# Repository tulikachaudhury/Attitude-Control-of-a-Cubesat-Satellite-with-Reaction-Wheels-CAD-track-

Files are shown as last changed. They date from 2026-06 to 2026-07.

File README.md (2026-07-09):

# Attitude-Control-of-a-Cubesat-Satellite-with-Reaction-Wheels-CAD-track-
Designing a 3U cubesat satellite with at T3 mutually perpendicular reaction wheels for attitude control, wheel mounting brackets, motor housing and structural supports. Ensure the design is dimensionally consistent and physically plausible.

<ins>The decision to use a 3U form factor</ins>
| Parameter | 1U | 2U | 3U |
| --- | --- | --- | --- |
| Volume | Small | Medium | Large |
| Wheel Integration | Difficult | Moderate | Easy |
| CAD Complexity | Easy | Medium | Medium |
| Realism | Moderate  | Good | Excellent |

The 1U form factor faces a volume crisis, allowing no room for a payload.
The 2U form factor does allow space for a small payload but the asymmetric physics due to the centre of mass lying between the 2 1U units make it an unfavourable choice. Moreover, the 2U form factor is much less common in the industry so it is hard to find references.
The 3U form factor ultimately wins out as the segments can be divided cleanly(payload, ADCS, avionics), and it solves the centre of mass and volume issues. The larger surface area also allows for massive power generation from solar panels. 
The 3U CubeSat has become the industry standard for commercial applications, offering the optimal balance between payload capacity, power generation, and cost-effectiveness. Companies like Planet Labs operate entire Earth observation constellations using 3U Dove satellites, while 6U and 12U platforms enable more sophisticated missions including deep space exploration and advanced propulsion systems.

<ins>The Design Process</ins>
The Chassis
The rails must be the longest part of the body, therefore a standoff offset of 2mm on either side is taken.
As stated in the Cal Poly blueprint, I have followed the standoff contact detail by using chamfer, and the max allowable protrusion on the faces is the rail width. Trusses between the rails ensure a lightweight and sturdy design, and fillets were added to the outer edges to ensure that sharp corners do not cause damage. Aluminium 6061 was my material of choice for the chassis

ACDS Design
Motor : EC22 Flat L High Torque
Reaction Wheel Diameter: 35m
Reaction Wheel Thickness: 8mm
The 3 mutually perpendicular wheels are placed at azimuths of 0 degrees, 120 degrees and 240 degrees. 

References:
International Journal of Aerospace
hexstaruniverse.com
nanoavionics.com

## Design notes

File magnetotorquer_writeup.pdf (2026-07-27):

## Magnetotorquer Design: The Math, the Logic, and the Numbers

Tulika Chaudhury

July 27, 2026

## Why we need these at all

The satellite has three reaction wheels, each tilted at cos⁻¹ (1/

√
3) ≈ 54.74◦
from the Z axis and
spaced 120◦ apart in azimuth. Dotting the three spin-axis unit vectors pairwise gives zero in all three cases, confirming they’re genuinely mutually orthogonal despite none of them lying along a body axis – a deliberate choice that gives equal torque and momentum capability in every direction using only three actuators.
Reaction wheels are excellent for fine pointing, but they only move angular momentum around – from the spacecraft body into the spinning wheel and back – they never get rid of it. Any small, steady external torque (gravity gradient, atmospheric drag, sunlight pressure, the satellite’s own stray magnetism) makes the wheels absorb momentum faster than they release it, and their speed creeps up orbit after orbit until one saturates and stops being able to produce torque at all. Magnetotorquers fix this because they push against something external – Earth’s magnetic field – so they can actually remove momentum rather than just shuffle it. They do two jobs: detumbling right after deployment, when body rates are too high for the wheels to safely absorb, and periodic momentum “dumping” during normal operation to keep the wheels in their healthy range.

## The physics, in plain terms

A current-carrying coil makes a magnetic dipole – a tiny switchable bar magnet – of strength

m = NIA, | (1)

where N is the turn count, I the current, and A the enclosed area. A magnetically soft core inside the coil concentrates the field and boosts this for the same current:

m = µrod NIAcore. | (2)

Immersed in Earth’s field B, that dipole feels a torque

τ = m × B. | (3)

The cross product matters: torque is always perpendicular to B, so a torquer can never twist the spacecraft about the direction the field happens to point at that instant. That’s why three axes are needed – between them, and as B rotates through the body frame over an orbit, they cover everything.

Why a rod doesn’t get the full benefit of its core

A finite rod partially cancels its own field at the ends – the same reason a short bar magnet is weaker than a long one of the same material. This self-demagnetization is captured by a demagnetizing factor Nd, which for a rod of length L, diameter d (aspect ratio ℓ = L/d) is approximately

Nd ≈

ln(2ℓ) − 1
ℓ

2

, | (4)

knocking the bulk material permeability µr down to an effective

µrod =

µr
1 + Nd(µr − 1). | (5)

The shorter the rod, the harder this bites.

How the satellite decides when and how hard to fire the coils

Detumbling. With only a magnetometer to work from, the standard approach is the B-dot law:

mcmd = −k B˙
body ≈ k (ω × B). | (6)

While tumbling fast, the field as seen by the satellite changes mostly because the satellite is spinning, not because the field itself moves. Commanding a dipole proportional to that apparent rate of change produces a torque that always opposes the part of the spin perpendicular to B – a magnetic brake needing nothing more than a magnetometer.

Momentum dumping. Once wheel momentum hw needs shedding, the desired de-saturation torque is τ des = −khhw. Since only the component perpendicular to B is achievable at any instant, the best available command is the projection

mcmd =

B × τ des
|B|

2

. | (7)

As B rotates through the body frame once per orbit, every component of hw eventually gets its turn to be perpendicular to the field, so it all comes off over time.

## How big does the dipole need to be?

Table 1: Worst-case steady disturbance torque, 500 km LEO.
Source | Size | Notes
Gravity gradient | 20.6 nN m | from the CAD inertia tensor
Aerodynamic drag | 43.2 nN m | 2 cm CG/CP offset
Solar radiation pressure | 4.9 nN m | smallest contributor
Residual spacecraft dipole | 400 nN m | dominates; 0.01 A m² residual
Total | 469 nN m | linear (conservative) sum

The satellite’s own stray magnetism – current loops in the avionics stack – dominates this budget, outweighing gravity, drag, and sunlight pressure combined (Figure 1).

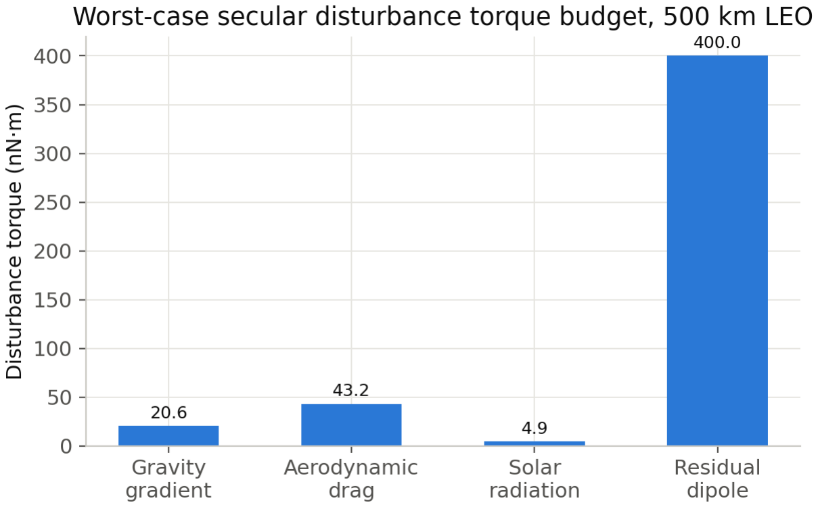
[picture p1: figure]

Figure 1: Where the disturbance torque comes from.

Sizing rule: double the disturbance torque for margin, and use the weakest field likely in orbit (near the geomagnetic equator, Bmin ≈ 25 µT at 500 km):

mreq =

2 τdist

Bmin

=

2 × 4.69 × 10⁻⁷
2.5 × 10⁻⁵

≈ 0.038 A m²
. | (8)

That’s the number every axis needs to beat.

## Sizing the actual hardware

X and Y use a 4 mm diameter steel core with a 14 mm outer diameter copper winding, 60 mm rod length, wound over 50 mm of it. Z runs along the 340.5 mm long axis of the 3U stack, so a rod there would be impractically long and would collide with the wheel array, avionics stack, and payload bay – an air-core coil bonded flat to the top bulkhead avoids that.

X/Y rods

Core cross-section: Acore = π(2mm)² = 1.257 × 10⁻⁵ m² . With L = 60 mm, d = 4 mm, the aspect ratio is ℓ = 15, so self-demagnetization matters:

Nd =

ln(30) − 1
15²

= 0.0107, µrod =

1000
1 + 0.0107(999) ≈ 86,

using µr = 1000 for the core steel. That’s how a bulk permeability of 1000 collapses to an effective 86 once the rod’s own shape is accounted for.
Design point: 600 turns of AWG28 magnet wire (0.36 mm insulated), 100 mA. Over the 50 mm winding length, AWG28 fits about 138 turns per layer, so 600 turns needs 5 layers – a 1.8 mm radial build-up, well inside the 5 mm annular space between core and coil OD. Resistance comes out to about 2.3 Ω, so each rod draws roughly 23 mW at 100 mA, and delivers

m = µrodNIAcore ≈ 0.065 A m² ,

about 70% above the 0.038 A m²
requirement.

Z air coil

No core, so µ = 1 in Eq. (2). Using an 80 mm outer diameter coil on the 100×100 mm top bulkhead, 100 turns of AWG28 at 100 mA:

Acoil = π(0.04 m)² = 5.03 × 10⁻³ m² , m = NIAcoil ≈ 0.050 A m² ,

about 32% above requirement. Wound as roughly 10 turns radially by 10 layers stacked (a compact ∼3.6 mm × 3.6 mm cross-section), it needs about 24 m of wire, giving R ≈ 4.9 Ω and P ≈ 49 mW at 100 mA.

Table 2: Magnetorquer design summary.
Axis | Construction | Turns | R (Ω) P @100mA | m delivered
X | 4mm core / 14mm coil, L=60mm | 600 | 2.3 | 23 mW | 0.065 A m²
Y | 4mm core / 14mm coil, L=60mm | 600 | 2.3 | 23 mW | 0.065 A m²
Z | 80mm air coil, top bulkhead | 100 | 4.9 | 49 mW | 0.050 A m²

All three clear the 0.038 A m²
requirement with margin (Figure 3), and total simultaneous power draw is under 100 mW – a rounding error against a typical 3U power budget. In practice the axes are usually pulsed one at a time, so real draw is lower.

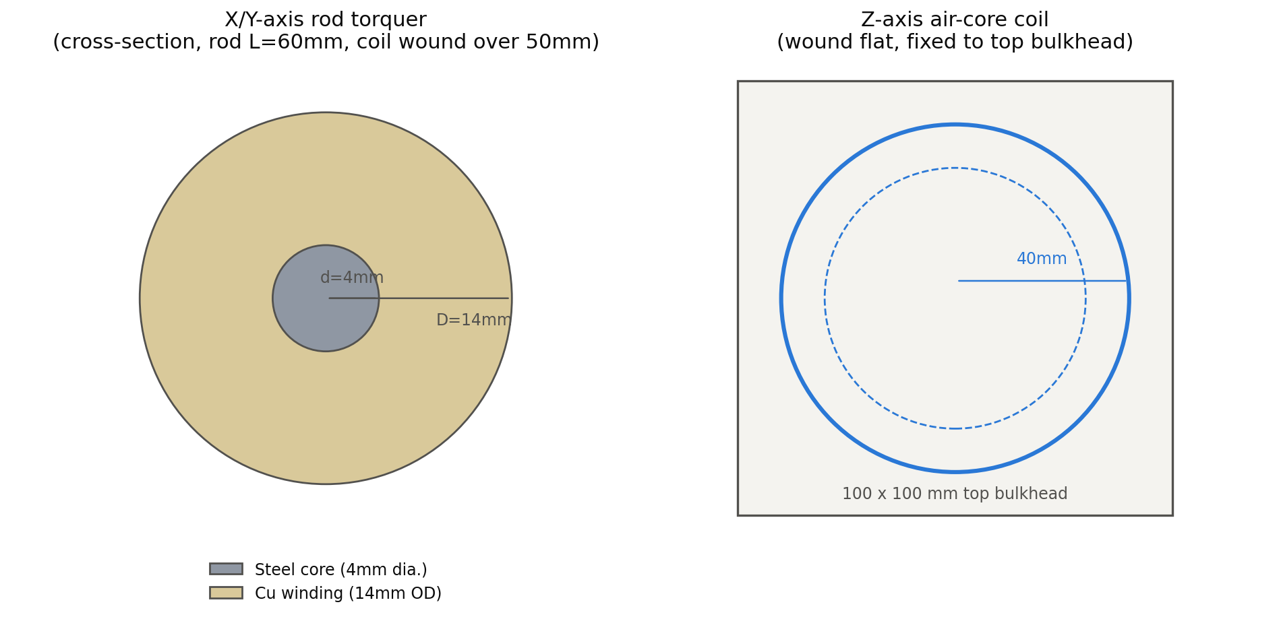
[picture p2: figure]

Figure 2: Left: rod cross-section. Right: the Z-axis coil’s footprint on the top bulkhead.

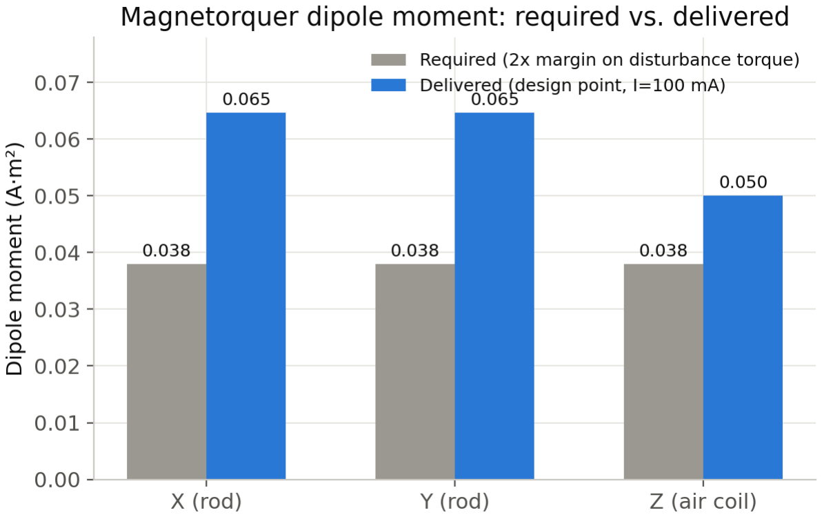
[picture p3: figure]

Figure 3: Required versus delivered dipole moment, by axis.

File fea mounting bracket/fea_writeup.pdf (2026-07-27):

## Reaction-Wheel Mounting Bracket: Launch-Load FEA

Tulika Chaudhury

July 27, 2026

## What this is and why it matters

Each of the satellite’s three reaction wheels sits in its own mounting bracket – an angled plate braced by two gussets, bolted down through a base flange, holding the Maxon ECX FLAT 22 L motor at the wheel’s spin-axis tilt. That tilt isn’t arbitrary: the three wheels are mutually orthogonal, each one skewed cos⁻¹
(1/

√
3) ≈ 54.74◦

from the Z axis, spaced 120◦ apart in azimuth. Measuring the actual motor-seating face directly off the CAD file gives an incline of 35.26◦ from the base plane –
which is exactly the complement of 54.74◦
, a nice confirmation that the bracket geometry matches the intended wheel orientation.
Before anything gets built, it’s worth asking a very ordinary question: will this bracket survive being launched? Rockets shake hard, and a small, light metal part cantilevered off a base plate is exactly the kind of thing that can crack or resonate itself apart if it’s under-designed. This is a finite-element analysis (FEA) of that bracket, run directly on the CAD file you uploaded – not a simplified stand-in – under a launch load case.

## The load case, explained

”Launch loads” for a small structure like this usually gets simplified to a quasi-static check: instead of simulating the actual shaking (a full random-vibration analysis), you pretend the whole structure is sitting in a very strong, steady gravity field and see if it survives. 12g is a standard, conservative number to use for this kind of check absent a specific launch-vehicle spec – it’s meant to be a worst-case stand-in for what several seconds of real vibration would do, not a literal prediction of any one moment.
We ran that 12g load three times, once pushing along each of the body’s X, Y, and Z axes, because a bracket that’s strong in one direction can be weak in another. On top of the 12g itself, we also add a safety factor of 1.25 when judging whether the design has survived – standard practice, so the reported margin already has some conservatism baked into it.
The load itself comes from two places: the bracket’s own (small) mass, and the motor plus one flywheel bolted to it – 32 g for the Maxon motor (from its published datasheet) plus 6.55 g for a flywheel (a quarter of the 26.2 g total across the wheel set), so 38.55 g all told. That mass is modeled as sitting rigidly on the four screw holes where the motor actually bolts on, offset about 10 mm out from the mounting face to approximate where the combined motor + flywheel center of gravity actually sits.

## How the model was built

The bracket was meshed with 24,332 nodes and 14,167 quadratic tetrahedral elements, refined down to 0.35 mm near the small bolt and screw holes where stress tends to concentrate. Every element passed a positive-Jacobian check before solving, meaning there are no inverted or degenerate elements corrupting the result.
For material, we used Aluminium 7075-T6 (E = 71.7 GPa, yield strength 503 MPa) as the primary case, since this is a stress-concentration region (gusseted corner, small bolt holes) – exactly where the stronger alloy earns its keep. We also checked Aluminium 6061-T6 (yield 276 MPa) side by side; the stress field itself barely changes between the two alloys (stress here depends on geometry and load, not much on which aluminum you pick), so this comparison is really just a second yieldstrength check, not a second analysis.
The base flange – the four bolt holes where the bracket clamps to the central mounting plate – was treated as fully fixed, standing in for a properly torqued bolted joint.

## What we found

Table 1: Peak stress, deflection, and margin of safety, by load direction.
Load case | Peak stress (raw) Peak stress (field)¹ Max deflection | MS, 7075-T6 | MS, 6061-T6
12g, +X | 1.37 MPa | 1.19 MPa | 0.12 µm | +293 | +160
12g, +Y | 2.56 MPa | 2.16 MPa | 0.23 µm | +156 | +85
12g, +Z | 2.83 MPa | 2.43 MPa | 0.21 µm | +141 | +77

Margin of safety here is MS = Sy/(1.25 × σvm) − 1, so a margin of, say, +150 means the part could handle roughly 150 times today’s stress before yielding. These numbers are enormous – deliberately so, because it’s worth showing rather than just asserting. A couple of milli-newtons of force spread across a few millimeters of aluminum just doesn’t add up to much stress, and that’s the honest physical reason, not an error. Figure 1 shows where that stress actually concentrates (the base flange corner nearest the bolt holes, exactly where you’d expect a clamped bracket foot to work hardest), and Figures 2–3 show the same numbers as charts.

1The raw column includes a node sitting exactly at a fixed-corner/bolt-hole edge – FEA reliably reports an artificially high, mesh-dependent stress right at a perfectly clamped sharp corner, which isn’t a physical material limit. The field column excludes those boundary nodes and is the more honest number; either way the story doesn’t change.

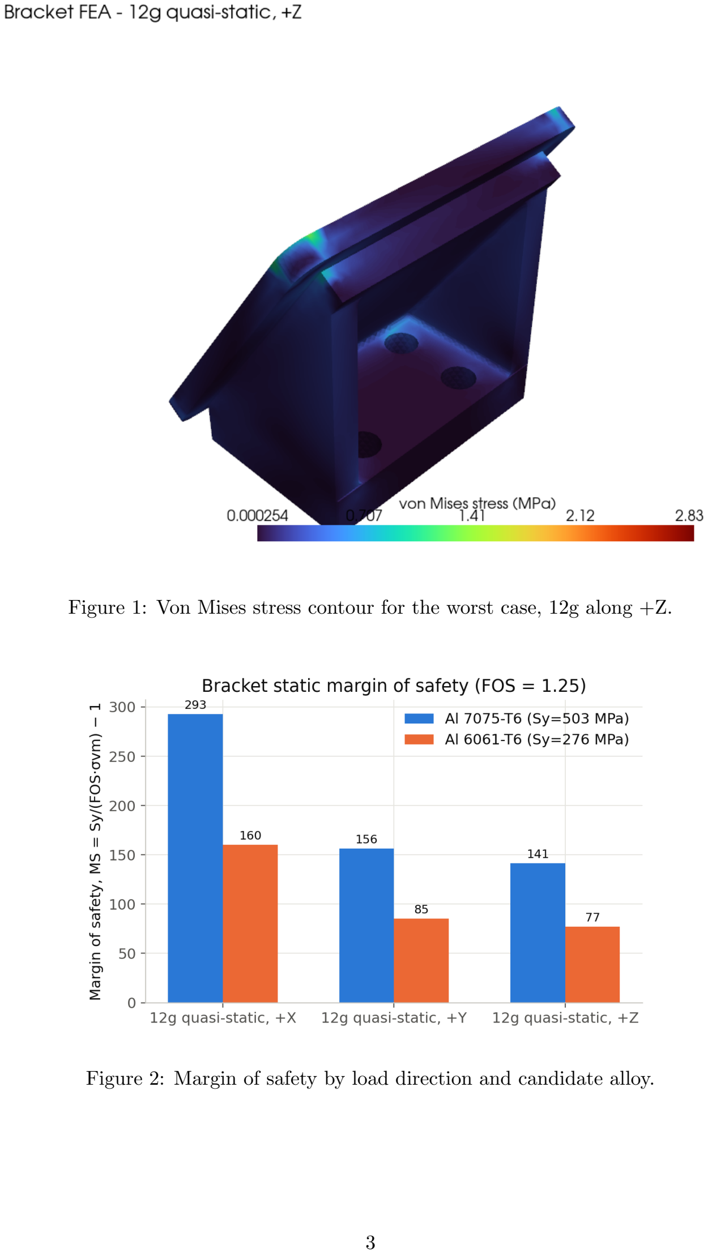
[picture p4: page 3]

Figure 1: Von Mises stress contour for the worst case, 12g along +Z.

Figure 2: Margin of safety by load direction and candidate alloy.

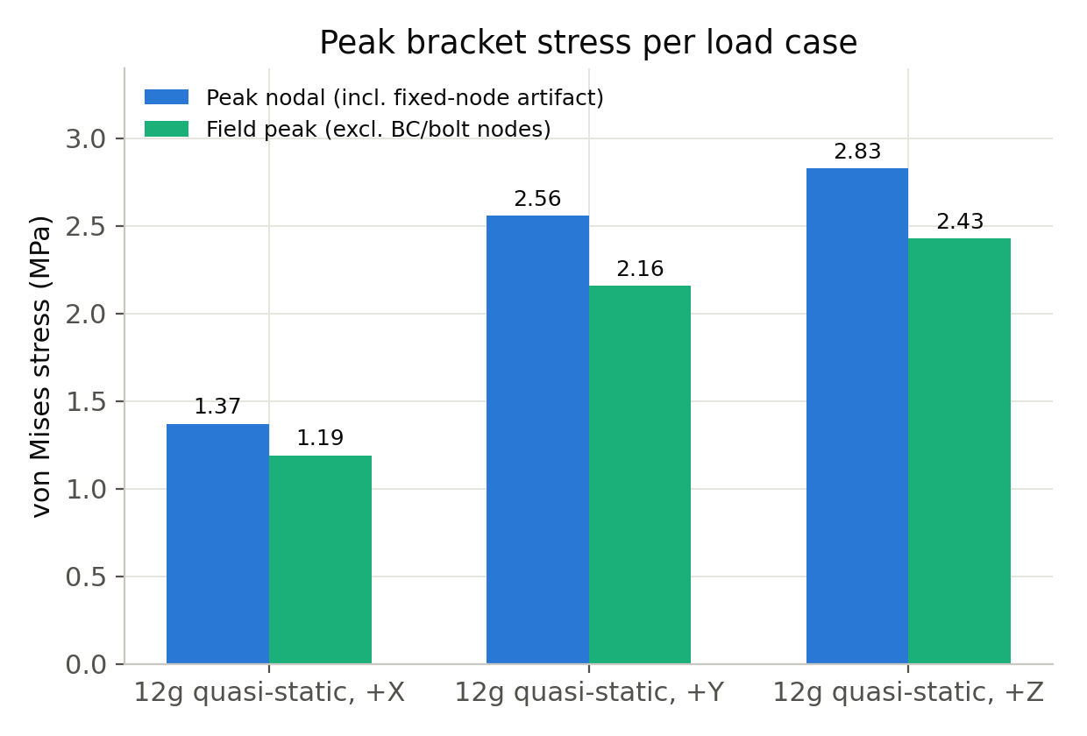
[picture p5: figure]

Figure 3: Peak stress per case: the raw (boundary-affected) number next to the more honest field number.

## The frequency check, and why it’s the number that actually matters here

Once the stress margins came back this large, stress stops being the interesting question. The thing that actually decides whether a small, stiff bracket like this survives a real launch is its natural frequency – how it wants to vibrate on its own. Rockets shake across a broad range of frequencies, and if a part’s natural frequency sits too low, it can resonate with that shaking and take far more damage than a simple g-load estimate would suggest, even if the static stress numbers look fine. Using the same fixed-base model with the motor and flywheel mass attached, the bracket’s first natural frequency comes out to about

f1 ≈ 4122 Hz,

which is comfortably – by a factor of 40 or so – above the roughly 100 Hz minimum stiffness that CubeSat deployer specifications typically require. This bracket is not going to be the thing that resonates on the way up.

## Limitations and scope

Two limitations are worth stating clearly, since they affect how these results should be read.
The 12g load case is a quasi-static approximation, not a full random-vibration analysis. It is the standard first screen for a structure of this size, and it is what launch loads means in this context, but a complete random-vibration (PSD) study remains the appropriate next step before the bracket can be considered launch-qualified.
The highest stress value in the raw results occurs at a mathematically singular point – a perfectly clamped sharp corner, where any finite-element model will report an artificially high, mesh-dependent stress that does not correspond to a physical material limit. Table 1 therefore reports both this raw value and a field value that excludes the boundary nodes responsible for the artifact; the conclusion is unchanged either way.

## Bottom line

The bracket clears launch quasi-static loading with very large margin in every direction tested, and its first natural frequency sits well clear of typical CubeSat stiffness requirements. It isn’t a structural risk item as designed – if anything, there may be room in a later iteration to shave material for mass savings, since the part is clearly over-built relative to what the loads actually demand.

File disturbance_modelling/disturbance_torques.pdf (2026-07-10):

## Environmental Disturbance Torques on a 3U CubeSat

ADCS Team — Simulation Track

July 10, 2026

Abstract

A reaction-wheel attitude control system must reject the small but persistent external torques that act on a spacecraft in low Earth orbit. This note derives, from first principles, the four dominant environmental disturbance torques for our 3U CubeSat reference mission (a 500 km Sun-synchronous orbit): the gravity-gradient torque, aerodynamic drag torque, solar radiation pressure torque, and residual magnetic torque. For each, we state the physical origin, derive the governing equation, and evaluate the order of magnitude for our platform. All four are of order 10⁻⁹ N m to 10⁻⁶ N m; over an orbit they pump momentum into the wheels, which is periodically removed by magnetorquer desaturation.

## 1 Reference Parameters

All numerical estimates use the reference mission and CAD-derived properties in Table 1.

Table 1: Reference orbit and spacecraft parameters.
Quantity | Symbol | Value
Orbit altitude | h | 500 km
Orbit radius | r | 6878 km
Orbital speed | v | 7613 m/s
Mean motion | n | 1.107 × 10⁻³ rad/s
Max transverse inertia | Imax | 1.405 × 10⁻² kg m²
Min inertia (spin axis) | Imin | 2.889 × 10⁻³ kg m²
Long-face area | A | 0.034 m²
Centre-of-pressure offset | rcp | 0.02 m
Earth magnetic field (LEO) B | 2 × 10⁻⁵ T to 5 × 10⁻⁵ T

The body-to-inertial rotation matrix built from the attitude quaternion q is written R(q); its transpose R(q)

⊤ maps an inertial vector into the body frame. All torques below are expressed in the body frame, because that is where Euler’s equation is integrated.

## 2 Gravity-Gradient Torque

Physical origin

Earth’s gravity is stronger on the near side of the spacecraft than the far side. For an extended body this differential pull produces a torque that tends to align the axis of minimum inertia with the local vertical.

Derivation

Model the body as a collection of point masses mi at positions r

c
i

relative to the centre of mass (CoM). The gravitational force on each is expanded to first order about the CoM,

Fi ≈ mi

g(r

c0
) + G(r

c0
) r

c
i
, | (1)

where G = ∂g/∂r is the gravity-gradient tensor at the CoM. The total torque about the CoM is L =

P
i

r

c
i × Fi

. The uniform part P
i mir

c
i
× g vanishes identically, because P
i mir

c
i = 0 by
the definition of the centre of mass. Only the gradient term survives; carrying out the sum (which turns the mass distribution into the inertia tensor J) and specialising to a spherical Earth gives the standard result
τgg = 3n

2 oˆ ×
J oˆ
(2)

where oˆ = R(q)

⊤ oˆinertial is the nadir (satellite → Earth) unit vector expressed in the body frame, and n is the orbital mean motion.

Key properties

The torque vanishes when a principal axis points at nadir, since then oˆ is an eigenvector of J and oˆ × Joˆ = 0. This is the basis of passive gravity-gradient stabilisation.

It is attitude-dependent: it must be recomputed every integration step.

Order of magnitude

The worst-case magnitude is

τ

max
gg =

3/2 n

2
Imax − Imin
=

3/2(1.107 × 10⁻³
)

2

(1.405 × 10⁻² − 2.889 × 10⁻³

) ≈ 2.1 × 10⁻⁸ N m. (3)

## 3 Aerodynamic Drag Torque

Physical origin

Even at 500 km the residual atmosphere exerts a drag force on the spacecraft. If the centre of pressure (CP) does not coincide with the CoM, this force produces a torque.

Derivation

The drag force opposes the velocity direction vˆ and has magnitude

Fdrag = −

1/2 ρ v² Cd A vˆ, | (4)

with ρ the local atmospheric density, v the orbital speed, Cd the drag coefficient (typically 2.2 for free-molecular flow), and A the projected frontal area. Expressed in the body frame and applied at the CP offset rcp from the CoM, the torque is

τaero = rcp ×

R(q)

⊤Fdrag
(5)

Order of magnitude

With ρ ≈ 5 × 10⁻¹³ kg/m³
(moderate solar activity), v = 7613 m/s, Cd = 2.2, A = 0.034 m² :

Fdrag =

1/2(5×10⁻¹³)(7613)²

(2.2)(0.034) ≈ 1.1×10⁻⁶ N, τaero ≈ Fdrag rcp ≈ 2.2×10⁻⁸ N m. (6)

Density varies by an order of magnitude with solar activity, so ρ is treated as a tunable parameter in the simulation.

## 4 Solar Radiation Pressure (SRP) Torque

Physical origin

Sunlight carries momentum; photons striking the spacecraft exert a small pressure. As with drag, an offset between the centre of pressure of the illuminated surface and the CoM converts this force into a torque.

Derivation

The solar radiation pressure at Earth’s distance is P = Φ/c, where Φ ≈ 1361W/m² is the solar
flux and c the speed of light, giving P ≈ 4.56 × 10⁻⁶ N m⁻²
. The force on an illuminated area As with reflectivity q (0 = perfectly absorbing, 1 = perfectly reflecting) is
Fsrp = −P (1 + q) As sˆ, | | (7)

with sˆ the Sun-to-spacecraft unit vector. The resulting torque about the CoM, with solar-pressure centre offset rcps, is

τsrp = rcps ×

R(q)

⊤Fsrp
(8)

The torque is present only in sunlight (zero during eclipse), so for a Sun-synchronous orbit it acts as a roughly once-per-orbit modulated disturbance.

Order of magnitude

With q = 0.6, As = 0.034 m² , rcps = 0.02 m:

Fsrp = (4.56 × 10⁻⁶

)(1.6)(0.034) ≈ 2.5 × 10⁻⁷ N, | τsrp ≈ 5.0 × 10⁻⁹ N m. | (9)

This is the smallest of the four for our platform, but for missions with large deployed solar panels (large As and rcps) it can dominate.

## 5 Residual Magnetic Torque

Physical origin

The spacecraft has a small residual magnetic dipole m arising from current loops, permanent magnets in components, and magnetised materials. This dipole interacts with Earth’s magnetic field B, producing a torque — the same physics the magnetorquers use deliberately for desaturation, here acting as an unwanted disturbance.

Derivation

The torque on a magnetic dipole m in an external field B is

τmag = m × B | (10)

where m is the body’s residual dipole (body frame, in A m²
) and B = R(q)

⊤Binertial is the local
geomagnetic field in the body frame. The field magnitude in LEO is B ≈ 2 × 10⁻⁵ T to 5 × 10⁻⁵ T and reverses roughly twice per orbit as the spacecraft crosses the magnetic equator, so this torque is strongly attitude- and position-dependent.

Order of magnitude

A typical uncompensated CubeSat residual dipole is m ≈ 0.01 A m²

to 0.05 A m²
. Taking m =
0.02 A m² and B = 3 × 10⁻⁵ T:

τmag ≈ (0.02)(3 × 10⁻⁵

) ≈ 6 × 10⁻⁷ N m. | (11)

This is often the largest of the environmental disturbances for a small satellite, which is why minimising the residual dipole (magnetic cleanliness) is a standard design driver.

## 6 Summary and Implications

Table 2 collects the four torques. All are of order 10⁻⁹ N m to 10⁻⁶ N m — individually tiny, but secular : acting continuously, they steadily accumulate angular momentum in the reaction wheels.

Table 2: Environmental disturbance torques for the 3U reference mission.
Disturbance | Governing equation | Magnitude (N m)
Gravity gradient | 3n
| 2 oˆ × (Joˆ) | ∼ 2 × 10⁻⁸
Aerodynamic drag | rcp × Fdrag | ∼ 2 × 10⁻⁸
Solar radiation press. | rcps × Fsrp | ∼ 5 × 10⁻⁹
Residual magnetic | m × B | ∼ 6 × 10⁻⁷

Momentum accumulation and desaturation. Because a reaction-wheel array conserves total angular momentum, any secular disturbance τd is absorbed by the wheels, whose stored momentum grows approximately linearly, hw(t) ≈ τd t. The wheels saturate at tsat = hmax/τd. For our platform (hmax ≈ 7 × 10⁻³ N m s) under the combined disturbances (∼ 7 × 10⁻⁷ N m worst case), tsat is of order a few hours, after which the magnetorquers must remove the accumulated momentum by applying a commanded τ = mcmd × B against Earth’s field. This is the physical justification for including magnetorquers in the ADCS architecture.

Modelling scope. The simulation implements the gravity-gradient and aerodynamic-drag torques directly (Eqs. 2 and 5), with all parameters exposed in the configuration file. Solar radiation pressure and magnetic torque are documented here for completeness and can be added as further terms in the same disturbance module; each reduces to a body-frame cross product of the form already implemented.

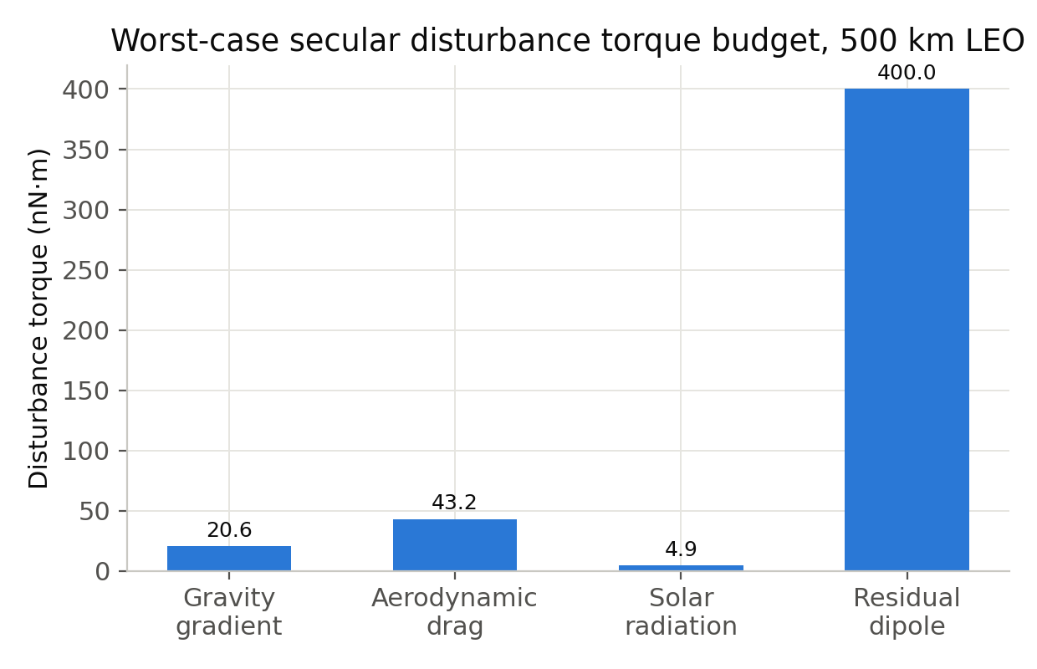
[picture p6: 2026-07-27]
fea mounting bracket/plot_disturbance_budget.png

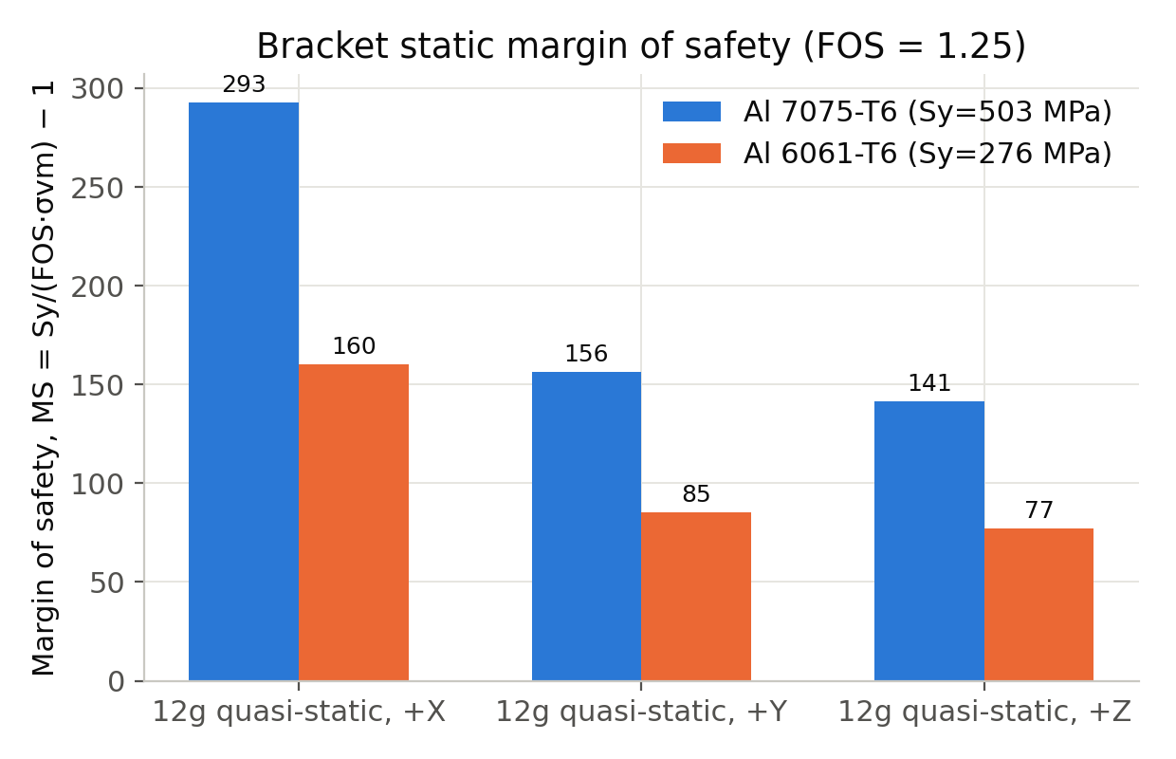
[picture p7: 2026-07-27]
fea mounting bracket/plot_margin_of_safety.png

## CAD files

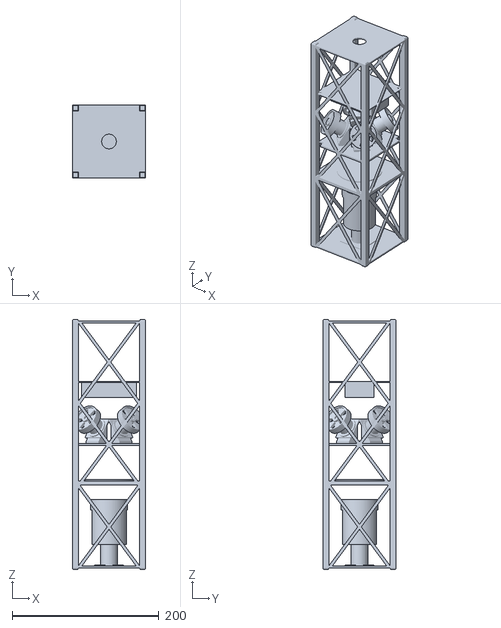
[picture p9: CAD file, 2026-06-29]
3U_Cubesat_Master_version2.stl
100.0 x 100.0 x 340.5

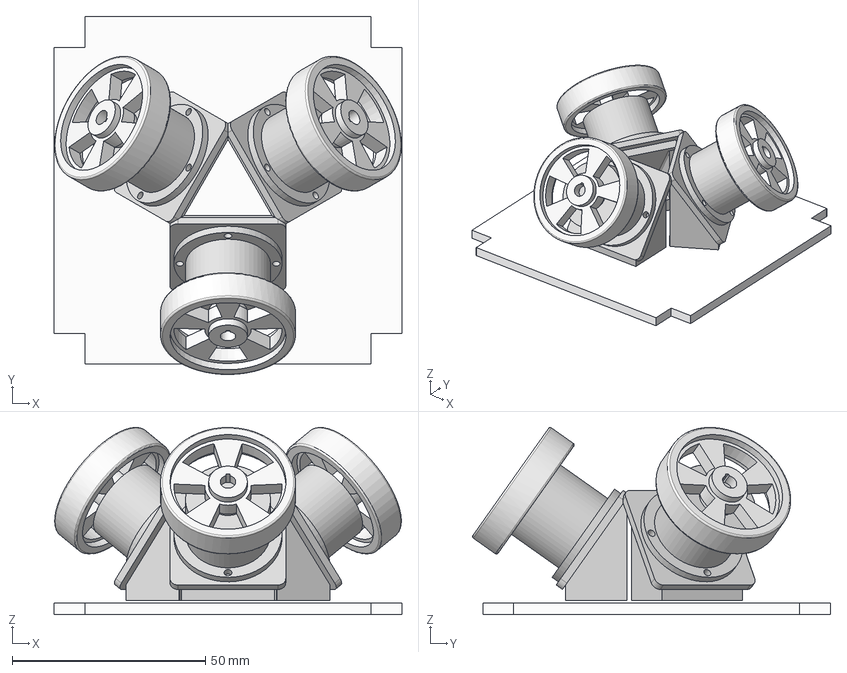
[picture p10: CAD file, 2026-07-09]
wheel assemblies/3 orthogonal reaction wheels pyramid setup.step
90.0 x 92.7 x 48.4 mm

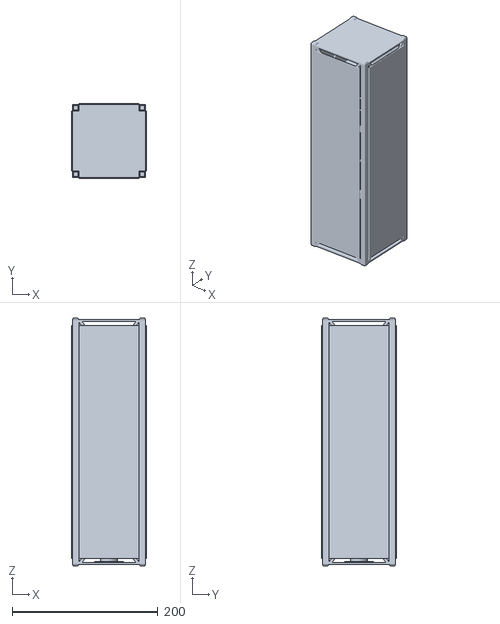
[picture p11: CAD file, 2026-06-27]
3U_Cubesat_Master_version1_toberefined.stl
103.2 x 103.2 x 340.5

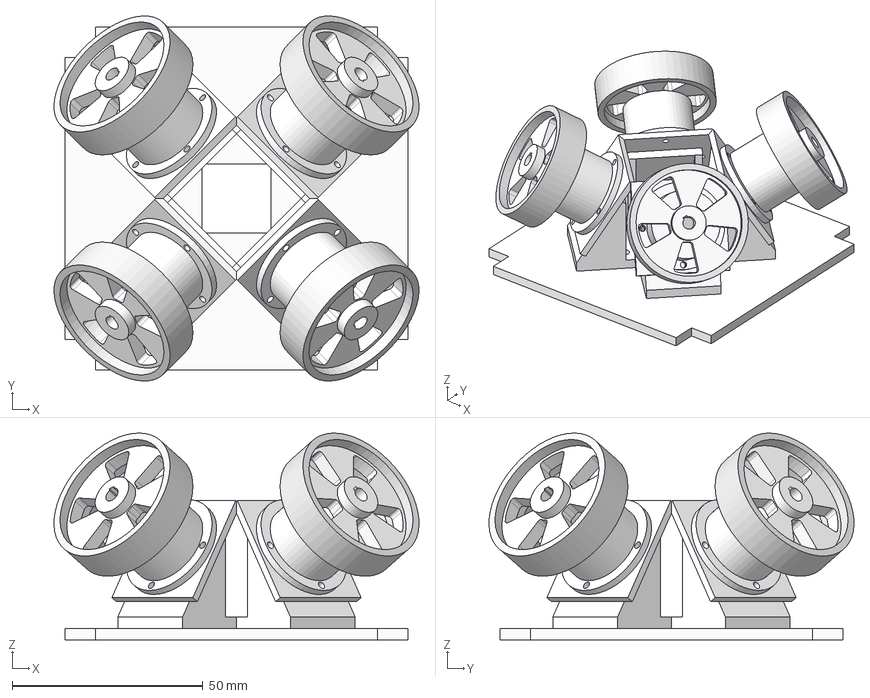
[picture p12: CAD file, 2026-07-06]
wheel assemblies/acds_system_pyramid.step
95.6 x 95.6 x 54.2 mm

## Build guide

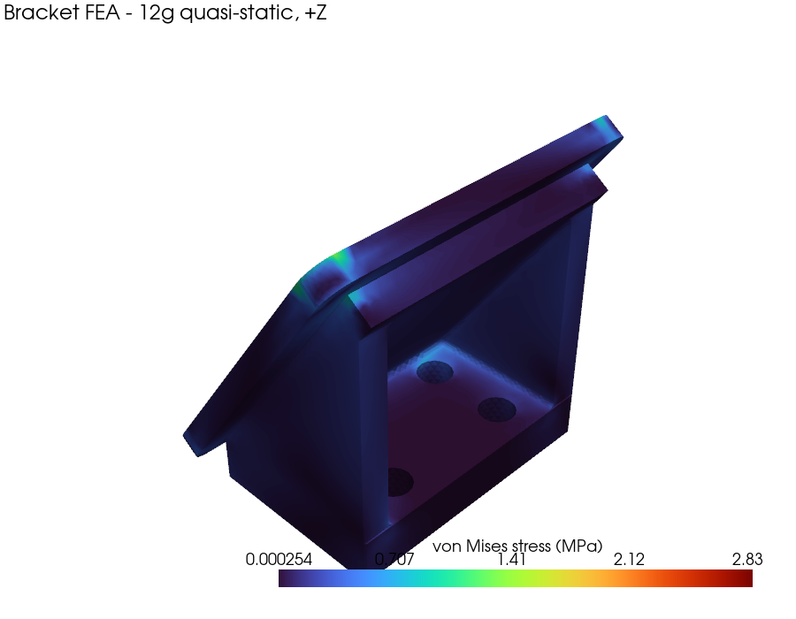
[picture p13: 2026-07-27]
fea mounting bracket/stress_step3.png
